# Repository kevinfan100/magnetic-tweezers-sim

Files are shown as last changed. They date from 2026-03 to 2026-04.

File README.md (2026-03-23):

# Magnetic Tweezers Simulation

ANSYS APDL magnetostatic finite element simulation of hexapole magnetic tweezers for biophysics research.

## Overview

This project implements FEM simulation of a 6-pole magnetic tweezers device, computing the magnetic field (B) under unit-excitation for each coil. Results feed into a point-charge model fitting pipeline for force calibration.

Based on: **Fei Long, "Design, Fabrication, and Calibration of a Hexapole Magnetic Tweezers," PhD Dissertation, Ohio State University, 2016.**

## Repository Structure

```
magnetic-tweezers-sim/
├── hexapole-long2016/       Long 2016 dissertation hexapole design
│   ├── apdl/                ANSYS APDL simulation & extraction scripts
│   ├── analysis/            MATLAB fitting & figure scripts
│   ├── data/                Fitting results (.mat)
│   ├── figures/             Publication figures (.png)
│   ├── docs/                Technical documentation
│   └── results/             ANSYS output (gitignored, ~10 GB/coil)
│
├── studies/                 Parametric & comparison studies
│   └── single-pole-yoke/   Yoke effect on single-pole B field
│
├── references/              Literature notes & paper management
│   ├── notes/               Structured Markdown notes (tracked)
│   ├── pdfs/                Original papers (gitignored)
│   └── texts/               pdftotext extracts (gitignored)
│
└── (future: hexapole-<name>/)  Additional hexapole designs
```

## Prerequisites

- **ANSYS MAPDL** 2025 R2 (or compatible version)
- **MATLAB** R2024b+ (Optimization Toolbox for fitting)
- ~60 GB disk space for full simulation results (6 coils)

## Quick Start

Run a single coil simulation (batch mode):
```bash
cd hexapole-long2016
"C:\Program Files\ANSYS2025R2\v252\ansys\bin\winx64\MAPDL.exe" -b -np 4 -m 24000 \
  -dir "results/coil1" -j "coil1" \
  -i "$(pwd)/apdl/MT_Modeling_Geometry_Meshing_Solving_Coil1.txt" \
  -o "results/coil1/solve.out"
```

Process results in MATLAB:
```matlab
cd hexapole-long2016/analysis
fit_charge_model        % [A] baseline fit
fit_all6_with_bias      % [B-6x] final 19-parameter fit
```

## Key Results (hexapole-long2016)

| Method | Parameters | Error | R_a (A/Wb) |
|---|---|---|---|
| [A] Baseline | ell=835 um | 4.94% | 9.21e8 |
| [J] Joint 6-coil | ell=766-818 um | 1.11% | ~1.01e9 |
| [B-6x] Final | 19 params | 0.07% | 1.03e9 |

## References

- Long, F. (2016). PhD Dissertation, Ohio State University.
- Zhang, Z. & Menq, C.H. (2011). IEEE/ASME Trans. Mechatronics.
- Long, F., Matsuura, T. & Bhatt, D. (2016). Actively Controlled Hexapole Electromagnetic Actuating System.

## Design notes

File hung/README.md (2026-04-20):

# Hung Hexapole Magnetic Tweezers — FEM Simulation

## Overview
ANSYS APDL magnetostatic simulation of the Hung hexapole magnetic tweezers design.
6 tilted poles on a R=0.5mm sphere at magic angle (54.74°), with 1018 steel (mu_r=280).

## Folder Structure

```
hung/
├── apdl/              APDL scripts
│   ├── MT_Hung_Simulate_Coil[1-6].txt        Original D-shape poles
│   ├── MT_Hung_Simulate_Coil1_filleted.txt    D-shape + R=40um fillet
│   ├── MT_Hung_Simulate_Coil1_filled.txt      Full-round sharp tip
│   ├── MT_Hung_Simulate_Coil1_round_filleted.txt  Full-round + R=40um fillet
│   ├── MT_Hung_SphereModel*.txt               IGES export scripts
│   ├── mesh_steel_only.txt                    Steel-only mesh (no air domain)
│   └── post_*.txt                             Post-processing scripts
├── analysis/          MATLAB scripts: data import, figure generation
├── comsol/            COMSOL models (gitignored)
├── docs/              Technical documentation
├── figures/
│   ├── analytic/      Analysis figures (sensor, fitting, parameter sweeps)
│   ├── geometry/      3D geometry annotations
│   ├── coil1/         Coil 1 B-field distribution figures
│   │   └── fail/      Rejected figures
│   └── coil2~6/       (empty, for future coil simulations)
│       └── fail/
├── IGES/              IGES exports: raw ANSYS output (unit flag=6)
├── IGES_converted/    IGES exports: unit flag=1 (SolidWorks compatible)
├── results/           ANSYS outputs (gitignored, ~10GB each)
└── scripts/           Utility scripts
```

## Pole Variants

| Script | Pole Shape | Tip | Status |
|---|---|-----|---|
| `Simulate_Coil1.txt` | D-shape | Sharp | Baseline |
| `Simulate_Coil1_filleted.txt` | D-shape + R=40um fillet | Rounded | Main model |
| `Simulate_Coil1_filled.txt` | Full-round | Sharp | Tested |
| `Simulate_Coil1_round_filleted.txt` | Full-round + R=40um fillet | Rounded | Tested |

## Design Parameters

| Parameter | Value |
|---|---|
| R_sphere | 0.5 mm |
| TILT_UP (P2,P4,P5) | 35° |
| TILT_DN (P1,P3,P6) | 5.71° |
| Pole total length | 43.0 mm |
| Pole shaft radius | 3.175 mm |
| Pole cone length | 15.875 mm |
| Tip fillet radius | 40 um |
| Coil R_in / R_out | 10 / 12 mm |
| Coil height | 15 mm |
| Turns | 70 |
| Steel mu_r | 280 |

## Key Results (Coil1, 70 A-turns, D-shape + fillet)

| Location | |B| |
|---|-----|
| WP center | 9.66 mT |
| P1 tip surface | 424 mT |
| Iron max (guide post) | 1493 mT |
| P1 surface (s=15.75mm) | 2.82 mT |

## Quick Start

```bash
cd hung

# Run simulation (D-shape + fillet, coil 1)
MAPDL -b -np 2 -m 8000 -dir "results/coil1/filleted" -j "coil1" \
  -i "apdl/sim/MT_Hung_Simulate_Coil1_filleted.txt" \
  -o "results/coil1/filleted/solve.out"

# Export B-field data
MAPDL -b -np 1 -m 4000 -dir "results/coil1/filleted" -j "coil1" \
  -i "apdl/postproc/post_export_data.txt"

# Generate figures (MATLAB)
run('analysis/generate_figures.m')
```

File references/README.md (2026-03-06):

# References

Reference papers for the magnetic tweezers ANSYS simulation project.

## How This Works

This folder uses a **notes-first** strategy for working with Claude Code:

| Tier | When | Action |
|---|---|---|
| **1. Notes** | 95% of cases | Read `notes/*.md` directly |
| **2. Targeted text** | Notes lack detail | Read `texts/*.txt` at specific line range (use `_page_index.txt` to locate pages), then update notes |
| **3. Full intake** | New paper added | Convert PDF via `pdftotext -layout`, read TOC, build skeleton note, deep-read key sections |

## Paper Index

<!-- Add papers here as they are processed. Citation key = note filename without .md -->

| Citation Key | Authors | Year | Type | Tags | Note Status |
|---|---|---|---|---|---|
| zhang-dissertation | Zhipeng Zhang | 2009 | PhD Dissertation | force-modeling, monopole-approximation, magnetic-circuit, calibration, quadrupole | complete |
| long-2016-dissertation | Fei Long | 2016 | PhD Dissertation | geometry, materials, fem-simulation, calibration, force-model, inverse-model, pole-naming, coil-design, superposition, hall-sensor | complete |
| zhang-2011-actuator-design | Z. Zhang, C.-H. Menq | 2011 | journal | geometry, materials, force-model, superposition, coil-design, pole-configuration, magnetic-circuit, inverse-model, calibration | complete |
| long-2016-active-control | F. Long, D. Matsuura, C.-H. Menq | 2016 | journal | geometry, materials, fem-simulation, calibration, force-model, inverse-model, optimal-control | complete |

## Topic Index

### Geometry & Device Design
- [zhang-dissertation](notes/zhang-dissertation.md) -- Quadrupole design: pole material (MuShield), dimensions, yoke
- [long-2016-dissertation](notes/long-2016-dissertation.md) -- Hexapole design: 1018 steel poles (40 um tip), 70-turn coils, 6-pole geometry, workspace 500 um
- [zhang-2011-actuator-design](notes/zhang-2011-actuator-design.md) -- Hexapole design: Ni-Fe-Mo foil poles (40 um tip, 178 um thick), 50-turn AWG#24 coils, rho=594 um, two-layer config
- [long-2016-active-control](notes/long-2016-active-control.md) -- Same 1018 steel hexapole as Long diss; FEM mesh in Fig. 2(b) is our ANSYS reference

### Materials & Magnetic Properties
- [zhang-dissertation](notes/zhang-dissertation.md) -- MuShield Ni-Fe-Mo alloy (mu_R=36000), cold rolled steel yoke (mu_R=5000), saturation ~0.9T
- [long-2016-dissertation](notes/long-2016-dissertation.md) -- 1018 low-carbon steel (>2T saturation), air reluctance 6.3e8 A/Wb, nonlinear B-H modeling
- [zhang-2011-actuator-design](notes/zhang-2011-actuator-design.md) -- Ni-Fe-Mo alloy poles (B_sat ~2.1 T), cold-rolled steel yoke, AWG#24 wire
<!--  -->

### FEM Simulation Methods
- [long-2016-dissertation](notes/long-2016-dissertation.md) -- ANSYS APDL magnetostatic, SOLID96/SOURC36, unit-excitation superposition, 6-solve approach
- [zhang-2011-actuator-design](notes/zhang-2011-actuator-design.md) -- References FEM for reluctance calibration (R_a=2.8e9 A/Wb), no FEM details given (see [18])
<!--  -->

### Calibration & Force Measurement
- [zhang-dissertation](notes/zhang-dissertation.md) -- PSD-based calibration, saturation current, inverse force model validation
- [long-2016-dissertation](notes/long-2016-dissertation.md) -- Flux distribution matrix K_I calibration, Hall-sensor force model, Langevin bead magnetization
- [zhang-2011-actuator-design](notes/zhang-2011-actuator-design.md) -- PSD-based k_I_hat calibration (0.53 pN at 1.2A), Brownian motion validation
<!--  -->

### Superposition & Field Computation
- [zhang-dissertation](notes/zhang-dissertation.md) -- Monopole approximation, superposition principle, quadratic force model F=Q^T*M*Q
- [long-2016-dissertation](notes/long-2016-dissertation.md) -- Magnetic charge model, quadratic force F=g*I^T*K^T*L*K*I, optimal inverse model, least-square position fitting
- [zhang-2011-actuator-design](notes/zhang-2011-actuator-design.md) -- Magnetic charge model, K_I matrix (5/6, 1/6), quadratic force F_hat=I_hat^T*N*I_hat, inverse model
<!--  -->

## Expected PDF Files

The following PDFs should be placed in `pdfs/` (gitignored, not tracked):

- `Design_and_Modeling_of_a_3-D_Magnetic_Actuator_for_Magnetic_Microbead_Manipulation.pdf` — Zhang & Menq, IEEE/ASME Trans. Mechatronics, 2011 (10 pp.)
- `Actively_Controlled_Hexapole_Electromagnetic_Actuating_System_Enabling_3-D_Force_Manipulation_in_Aqueous_Solutions.pdf` — (12 pp.)
- `Fei Long_dissertation.pdf` — Long, PhD Dissertation, Ohio State University, 2016 (167 pp.)
- `Zhipeng Zhang.pdf` — Zhang, PhD Dissertation (165 pp.)

## Text Extraction

PDFs are converted to text using Poppler's `pdftotext -layout` and stored in `texts/` (gitignored).
Each text file has a `_page_index.txt` that maps PDF page numbers to line numbers.

To regenerate all text files:
```bash
PBIN="C:/Users/pmero/AppData/Local/Microsoft/WinGet/Packages/oschwartz10612.Poppler_Microsoft.Winget.Source_8wekyb3d8bbwe/poppler-25.07.0/Library/bin"
for f in references/pdfs/*.pdf; do
  "$PBIN/pdftotext.exe" -layout "$f" "references/texts/$(basename "$f" .pdf).txt"
done
```

## Adding a New Paper

1. Place PDF in `pdfs/` with naming convention: `firstname-year-short-topic.pdf`
2. Run `pdftotext -layout` to generate text extract in `texts/`
3. Generate page index: `awk 'BEGIN{page=1; print "Page 1: line 1"} /\f/{page++; print "Page " page ": line " NR}' texts/name.txt > texts/name_page_index.txt`
4. Copy `notes/_TEMPLATE.md` to `notes/firstname-year-short-topic.md`
5. Read the TOC from text file and build a skeleton note
6. Fill in key sections based on project needs
7. Update the Paper Index and Topic Index tables above

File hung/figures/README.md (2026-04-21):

# Hung Hexapole — Figures

## Folder Structure

```
figures/
├── coil1/ ~ coil6/    B-field distribution plots per single-coil excitation
│   └── fail/          Rejected or superseded versions of those plots
├── analytic/          Analysis figures: fitting, geometry, sensor sensitivity
└── README.md          This file
```

**Convention** (per project figure-organization rule):
- Successful distribution plots go in the `coilN/` root and **overwrite the previous file with the same name**.
- Rejected / superseded versions move to `coilN/fail/`.
- Analysis, parameter-sweep, geometry-annotation, and sensor-study figures live in `analytic/` (not coil-specific).

Currently only **coil1/** has populated B-field plots; coil2–6 have empty `fail/` subfolders reserved.

## coil1/ — B-field plots (D-shape + 40 µm fillet, 70 A-turns)

| File | Description |
|---|---|
| `Bvector_topview.png` | Top-view B-field vectors over the full model (±80 mm, Tesla) |
| `Bvector_topview_mT.png` | Same top view, rescaled to mT (close-up near working point) |
| `Bvector_3D_iron.png` | 3D B-field arrows inside iron only, showing flux circulation |
| `Bcontour_P1_topview.png` | \|B\| contour at P1 tip top view |
| `Bcontour_xaza_Dfillet.png` | \|B\| contour on x_a-z_a plane (y_a=0), D+fillet 3-pass NREFINE data, 2D slab interpolation. Actuator frame: x_a→P1, y_a→P3, z_a→P5 |
| `Bcontour_xaza_Dfillet_smooth.png` | Same view, upgraded with 3D interpolation + Gaussian smoothing; clearest production version (WP = 8.74 mT, 526,645 nodes) |
| `Bcontour_xaza_Dshape_baseline.png` | Same view, D-shape **no fillet / no NREFINE** baseline (368,686 nodes, WP = 9.31 mT) — shown as convergence contrast to `_smooth` |

## analytic/ — Fitting & analysis figures

### Point-charge model fitting
| File | Description |
|---|---|
| `charge_model_cost_landscape.png` | Method [A] cost vs ell (1D search landscape) |
| `charge_positions_J.png` | 6 fitted charge positions from Method [J] ideal K_I |
| `charge_projection_lower_upper.png` | Lower/Upper charge projection schematic (s, θ, l relationship) |
| `fitting_J_idealKI_quiver_error.png` | [J] ideal K_I: FEM vs model quiver + % error scatter |
| `fitting_J_idealKI_RMSE.png` | [J] ideal K_I: FEM vs model quiver + RMSE (mT) |
| `fitting_J_idealKI_50um_RMSE.png` | [J] ±50 µm cube (Long-compatible) + RMSE |
| `fitting_B6x_quiver_error.png` | [B-6x] alternating superposition: FEM vs model quiver + error |

### Direction vectors (d̂)
| File | Description |
|---|---|
| `dhat_vs_pole_axis.png` | d̂ (WP→charge) vs pole axis direction, Hung |
| `dhat_vs_pole_axis_Long.png` | Same comparison for Long 2016 (reference) |
| `dhat_3D_Long.png` | 3D view of Long 2016 d̂ vectors |

### Hall-sensor analysis
| File | Description |
|---|---|
| `sensor_sensitivity_full.png` | Sensor sensitivity vs position, full range with installable annotation |
| `sensor_sensitivity_vs_position.png` | Same, zoomed to installable range |
| `sensor_ratio_fit.png` | Sensitivity ratio fit curve |
| `sensor_ratio_vs_distance.png` | Sensitivity ratio vs sensor-to-WP distance |
| `sensor_Btop_full_range.png` | B-field magnitude at sensor top surface, full range |
| `sensor_Btop_vs_position.png` | Same, zoomed |

### Geometry annotations
| File | Description |
|---|---|
| `hexapole_tip_annotated.png` | 6 pole tips on R=0.5 mm sphere with P1–P6 labels and l annotation |
| `mesh_steel_filleted_3D.png` | 3D mesh visualization of steel body (D-shape + fillet, no yoke) |

### Mesh convergence
| File | Description |
|---|---|
| `WP_convergence_Hung.png` | WP \|B\| vs total mesh node count: baseline (no NREFINE, 368k, 9.31 mT) → 3-pass NREFINE (526k, 8.74 mT); Richardson asymptote ≈ 8.60 mT |

## Generating Figures

Paths reflect the current post-reorg structure:

```bash
# Step 1: Run ANSYS simulation (D-shape + fillet, coil1)
cd hung/
"C:\Program Files\ANSYS2025R2\v252\ansys\bin\winx64\MAPDL.exe" -b -np 4 -m 8000 \
  -dir "results/coil1/filleted" -j "coil1" \
  -i "apdl/sim/MT_Hung_Simulate_Coil1_filleted.txt" \
  -o "results/coil1/filleted/solve.out"

# Step 2: Export B-field data for MATLAB
"C:\Program Files\ANSYS2025R2\v252\ansys\bin\winx64\MAPDL.exe" -b -np 1 -m 4000 \
  -dir "results/coil1/filleted" -j "coil1" \
  -i "apdl/postproc/post_export_data.txt"

# Step 3: Generate plots in MATLAB
cd analysis/plot
# In MATLAB:
#   run('plot_Bfield_2d.m')      -> figures/ root (move to figures/coil1/)
#   run('plot_Bfield_3d.m')      -> Bvector_3D_iron.png
#   run('plot_J_quiver.m')       -> figures/analytic/fitting_J_idealKI_quiver_error.png
#   run('plot_J_rmse.m')         -> figures/analytic/fitting_J_idealKI_RMSE.png
#   run('plot_charge_proj.m')    -> figures/analytic/charge_projection_lower_upper.png
#   run('plot_Bcontour_xaza.m')          -> figures/coil1/Bcontour_xaza_Dfillet_smooth.png
#   run('plot_Bcontour_xaza_baseline.m') -> figures/coil1/Bcontour_xaza_Dshape_baseline.png
```

Note: `plot_Bfield_2d.m` and `plot_Bfield_3d.m` save to the `figures/` root — manually move the output into the appropriate `coilN/` subfolder after each run.

## Simulation Parameters

| Parameter | Value |
|---|---|
| Excitation | 70 A-turns (TURNS=70, I=1 A) |
| Steel mu_r | 280 (linear, constant) |
| Pole shape | D-shape + 40 µm diameter tip fillet |
| Mesh | tips fine → steel ~ coarse air |
| Solver | magsolv,3 (DSP) |

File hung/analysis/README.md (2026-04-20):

# MATLAB Analysis Scripts

## Prerequisites
- Run ANSYS simulation first (`MT_Hung_Simulate_CoilN_filleted.txt`) for all 6 coils
- Run data export (`post_export_data_coilN.txt`) to produce `.dat` files in `results/coilN/filleted/`

## Directory Structure

```
hung/analysis/
├── core/        Shared utilities (constants, data loader)
├── fit/         Charge-model fitting pipeline ([pre-J] → [J] → [B-6x])
├── plot/        Figure generation (B-field, quiver error, RMSE, projection)
├── util/        Small helpers (position printout)
└── variants/    Alternative or previous-version scripts (not actively used but may be revisited)
```

## Scripts

### core/ — shared utilities
| File | Description |
|---|---|
| `mt_constants.m` | Hung hexapole design constants: R_norm, tip positions, yoke dimensions, pole angles |
| `import_ansys_data.m` | Read ANSYS-exported coordinate + B-field `.dat` files. Handles MAPDL banner headers and concatenated negative numbers. Returns struct with node_id, x, y, z, bx, by, bz, bsum |

### fit/ — fitting pipeline
Run in this order. Each script is independent but later steps load outputs from earlier ones.

| Order | File | Output | Description |
|---:|---|---|---|
| 1 | `fit_ell_percoil.m` | `single_charge_ell.mat` | Per-coil single-charge ell sweep (no K_I), gives rough |l| per pole |
| 2 | `fit_ell_perlayer.m` | `KI_fit.mat` | Per-layer ell averages + sphere `pos` initial values for [J] |
| 3 | `fit_J.m` | `J_ideal_fit.mat` | **[J] Joint 6-coil fit with ideal K_I** — main result (err ~0.46%). Needed as init by B6x_1C/6C. |
| 3a | `fit_J_50um.m` | `J_idealKI_50um.mat` + figure | [J] restricted to ±50 μm cube (Long-compatible) + RMSE figure |
| 4 | `fit_B6x_1C.m` | `B6x_hung_1C.mat` | [B-6x] 18 pos + 1 shared C (VarPro). Loads `J_ideal_fit.mat` and `KI_fit.mat`. |
| 4a | `fit_B6x_6C.m` | `B6x_hung_6C.mat` | [B-6x] 18 pos + 6 per-pole C (linear LS). Same loads as 4. |
| 4b | `fit_B6x_allcoil.m` | `all6_bias_fit.mat` | [B-6x] all-coil superposition, requires `charge_model_fit.mat` (no Hung producer — see `data/README.md`) |

### plot/ — figures
| File | Output | Description |
|---|---|---|
| `plot_Bfield_2d.m` | `figures/Bvector_topview.png`, `Bfield_xy.png`, `Bfield_xz.png` | Long2016-style vector + contour plots |
| `plot_Bfield_3d.m` | `figures/Bfield_3d.png` | 3D B-field arrow plot (iron flux flow) |
| `plot_J_quiver.m` | `figures/analytic/fitting_J_idealKI_quiver_error.png` | [J] FEM vs Model quiver + % error |
| `plot_J_rmse.m` | `figures/analytic/fitting_J_idealKI_RMSE.png` | [J] FEM vs Model quiver + RMSE (mT) |
| `plot_charge_proj.m` | `figures/analytic/charge_projection_lower_upper.png` | Lower/Upper charge projection schematic |

### util/
| File | Description |
|---|---|
| `print_J_positions.m` | Print per-pole positions table from [J] ideal K_I fit |

### variants/ — alternative versions, kept available for future use
These are not part of the current main pipeline, but are kept intact (paths already adjusted) so you can re-run them when needed (e.g., to re-check a previous method against the current main one, or to explore an alternative).

| File | Current main | Context / when to use |
|---|---|---|
| `fit_KI_v1.m` | `fit/fit_ell_perlayer.m` | v1 uses single ell from method [A]; v2 uses per-layer ell. Re-run v1 if you want to compare the single-ell path. |
| `fit_J_fittedKI.m` | `fit/fit_J.m` | Uses **fitted** K_I; main pipeline uses **ideal** K_I (0.46% error, confirmed sufficient). Re-run if you want to revisit non-ideal K_I behaviour. |

## Path Mechanism

Each active script adds `core/` to the MATLAB path automatically:

```matlab
addpath(fullfile(fileparts(mfilename('fullpath')), '..', 'core'));
```

This lets you `cd` into `fit/` (or `plot/`, `util/`) and run scripts directly without prior setup.

## Usage Example

```matlab
% Generate B-field figures for coil1
cd hung/analysis/plot
run('plot_Bfield_2d.m')
run('plot_Bfield_3d.m')

% Run full fitting pipeline
cd ../fit
run('fit_ell_percoil.m')     % produces single_charge_ell.mat
run('fit_ell_perlayer.m')    % produces KI_fit.mat (needed by later steps)
run('fit_J.m')               % produces J_ideal_fit.mat (needed by B6x_1C/6C)
run('fit_B6x_1C.m')          % [B-6x] with shared C
run('fit_B6x_6C.m')          % [B-6x] with per-pole C

% Plot fitting error
cd ../plot
run('plot_J_quiver.m')
run('plot_J_rmse.m')
```

Output `.mat` files go to `hung/data/`. Output `.png` files go to `hung/figures/` (2D/3D B-field) or `hung/figures/analytic/` (fitting error, projection).

## Data Format
The `.dat` files produced by `post_export_data_coilN.txt`:
- `coilN_coord_{all,wp}.dat` — node coordinates (NODE, X, Y, Z)
- `coilN_bfield_{all,wp}.dat` — B-field (NODE, BX, BY, BZ, BSUM)
- WP region = nodes within 2 mm of origin
- Units: SI (meters, Tesla)

## Figure Style (matching Long2016)
- Font: Helvetica, 12pt labels, 13pt titles
- Colormap: turbo(256)
- DPI: 300 (figures), 400 (3D)
- Contour: 20 levels, no line edges

## Legacy → New Filename Mapping

For anyone looking up old filenames referenced in git history or documentation:

| Old | New |
|-----|-----|
| `fit_single_charge.m` | `fit/fit_ell_percoil.m` |
| `fit_KI_v2.m` | `fit/fit_ell_perlayer.m` |
| `test_J_idealKI.m` | `fit/fit_J.m` |
| `fit_J_idealKI_50um.m` | `fit/fit_J_50um.m` |
| `fit_B6x_hung.m` | `fit/fit_B6x_1C.m` |
| `fit_B6x_perC.m` | `fit/fit_B6x_6C.m` |
| `fit_all6_with_bias.m` | `fit/fit_B6x_allcoil.m` |
| `generate_figures.m` | `plot/plot_Bfield_2d.m` |
| `generate_fig_3d.m` | `plot/plot_Bfield_3d.m` |
| `plot_J_idealKI.m` | `plot/plot_J_quiver.m` |
| `plot_J_idealKI_RMSE.m` | `plot/plot_J_rmse.m` |
| `plot_charge_projection.m` | `plot/plot_charge_proj.m` |
| `print_J_idealKI_positions.m` | `util/print_J_positions.m` |
| `fit_KI.m` | `variants/fit_KI_v1.m` |
| `fit_joint_6coil.m` | `variants/fit_J_fittedKI.m` |
| `plot_fitting_J.m` | *(deleted — obsolete figure also removed)* |

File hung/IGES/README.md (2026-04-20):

# IGES Part Exports

## Description
Individual part IGES files exported from ANSYS with SolidWorks-compatible units (MM=1/25.4).
SolidWorks reads values as inches x 25.4 = correct mm dimensions.

## Files

| File | Part | Key Dimensions |
|---|---|---|
| `Mag_Pole_Bottom.iges` | Magnetic pole (D-shape + cone) | R=3.175mm, cone=15.875mm, total=43mm, flat=28mm |
| `Pole_Block_Top.iges` | Upper block (L-shape) | 25x22x10mm, penetration=7mm |
| `Pole_Block_Bottom.iges` | Lower block (L-shape) | 22x22x10mm, penetration=4.5mm |
| `Mag_Guide_Post.iges` | Guide post cylinder | R=4mm, H=46mm |
| `Coil.iges` | Excitation coil ring | R_in=10mm, R_out=12mm, H=15mm |
| `Upper_Ring.iges` | Yoke (iron ring) | R_in=38mm, R_out=62.5mm, T=2mm |
| `Full_Assembly.iges` | Complete hexapole assembly | All parts assembled, unit flag=1 (inches) |
| `Mag_Pole_Bottom_filleted.iges` | Pole with 40 um diameter tip fillet (single part) | R_tip=20um, semi-angle 11.31°, junction at 15.793mm |
| `Full_Assembly_filleted.iges` | Complete assembly with 40 um tip fillet on all 6 poles | Same as above for all poles |

## STEP Conversion
To convert to STEP for other CAD software:
1. Open IGES in SolidWorks (dimensions will be correct mm)
2. File → Save As → .STEP

`Full_Assembly.iges` has unit flag fixed to 1 (inches) for reliable STEP conversion.

## Regenerating
When part dimensions change:
1. Update values in `hung/apdl/geom/export_parts.txt`
2. Run: `MAPDL -b -np 1 -m 2000 -dir "IGES" -j "parts" -i "apdl/geom/export_parts.txt"`
3. For full assembly: run `apdl/variants/MT_Hung_SphereModel.txt`, copy output to `Full_Assembly.iges`, fix unit flag with `sed -i "s/,1.0,6,,/,1.0,1,,/" Full_Assembly.iges`

## Filleted Versions (40 um diameter tip fillet)

The `_filleted.iges` versions add a 40 um diameter (20 um radius) spherical fillet at each pole tip,
replacing the mathematically sharp point with a smooth rounded tip.

**Why fillet?** Real machined parts cannot have R=0 sharp tips. EDM machining typically achieves
20-50 um. Adding a fillet matches reality and improves FEM mesh stability at the tip.

**Geometry (Method A — smooth tangent):**
- Foremost point of fillet at original tip position (preserves R=0.5mm sphere constraint)
- Cone semi-angle unchanged at 11.31° (matches original Hung STEP)
- Cone-cyl junction shifts back from 15.875 -> 15.793 mm (delta = 0.082 mm)
- Total pole length unchanged at 43 mm
- All other features (flat at 28mm, far end at 43mm, POLE_R=3.175mm) unchanged

**Constraints preserved:**
- All 6 fillet foremost points still on R=0.5mm sphere
- Orthogonal pair axes still 90 degrees
- tip-to-tip distance still 1.0 mm
- Magic angle 54.74 deg unchanged

**To regenerate:**
- Single pole: `MAPDL ... -i apdl/geom/export_pole_filleted.txt`
- Full assembly: `MAPDL ... -i apdl/geom/MT_Hung_Assembly_Dfillet.txt`

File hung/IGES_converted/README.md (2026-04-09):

# IGES Converted — Unit Flag Fixed

## Description
Same parts as `hung/IGES/`, but with IGES unit flag corrected from 6 (mm) to 1 (inches).
This ensures reliable conversion when saving as STEP in SolidWorks or other CAD software.

## Difference from `hung/IGES/`
- `hung/IGES/` — raw ANSYS export, unit flag = 6 (mm), values in inches. SolidWorks opens correctly but STEP conversion may fail.
- `hung/IGES_converted/` — unit flag fixed to 1 (inches). SolidWorks opens correctly AND STEP conversion preserves dimensions.

## Files

| File | Description |
|---|---|
| `Mag_Pole_Bottom.iges` | Magnetic pole (D-shape + cone) |
| `Pole_Block_Top.iges` | Upper block (L-shape) |
| `Pole_Block_Bottom.iges` | Lower block (L-shape) |
| `Mag_Guide_Post.iges` | Guide post (R=4mm, H=46mm) |
| `Coil.iges` | Excitation coil (R_in=10, R_out=12, H=15mm) |
| `Upper_Ring.iges` | Yoke ring (R_in=38, R_out=62.5, T=2mm) |
| `Full_Assembly.iges` | Complete hexapole assembly |
| `Mag_Pole_Bottom_filleted.iges` | Pole with 40 um diameter tip fillet (single part) |
| `Full_Assembly_filleted.iges` | Complete assembly with 40 um tip fillet on all 6 poles |

## Units
All files: values in inches, unit flag = 1 (inches).
SolidWorks reads as inches x 25.4 = correct mm dimensions.

## Regenerating
When parts change, re-export from `hung/IGES/` and fix unit flag:
```bash
cp hung/IGES/Part.iges hung/IGES_converted/Part.iges
sed -i "s/,1.0,6,,/,1.0,1,,/" hung/IGES_converted/Part.iges
```

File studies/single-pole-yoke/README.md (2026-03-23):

# Single-Pole Yoke Effect Study

Quantifies how the iron yoke affects the magnetic field of a single pole (P1).

## Comparison

| Metric | Case A (bare pole) | Case B (pole + yoke) | Ratio |
|---|---|---|---|
| B at WP center | 0.646 mT | 6.174 mT | 9.55x |
| Max B in WP | 18.3 mT | 213.8 mT | 11.7x |

## Key Findings

1. **Field Enhancement**: Yoke provides ~9.6x enhancement at workspace center
2. **Shape Preserved**: Normalized axial profile correlation = 0.9989 — yoke mainly affects magnitude, not spatial distribution
3. **Magnetic Circuit**: Simple series reluctance model underestimates the effect; yoke acts as a flux collector, not just a return path
4. **Effective R_a**: Bare pole R_a = 1.24e10, with yoke R_a = 1.29e9 (ratio matches field enhancement)

## Files

- `apdl/MT_SinglePole_Only.txt` — Case A: bare pole + coil, no yoke
- `apdl/MT_SinglePole_WithYoke.txt` — Case B: pole + coil + yoke
- `apdl/post_view_Bfield.txt` — POST1 visualization (GUI)
- `analysis/compare_yoke_effect.m` — V1 (enhancement) + V2 (distribution) + V3 (magnetic circuit)
- `data/yoke_comparison.mat` — Saved results
- `figures/` — B field contour and vector plots

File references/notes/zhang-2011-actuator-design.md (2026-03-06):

# Design and Modeling of a 3-D Magnetic Actuator for Magnetic Microbead Manipulation

## Bibliographic Info

| Field | Value |
|---|---|
| Authors | Zhipeng Zhang (Member, IEEE) and Chia-Hsiang Menq (Senior Member, IEEE) |
| Year | 2011 |
| Type | journal |
| Source | IEEE/ASME Transactions on Mechatronics, Vol. 16, No. 3, June 2011, pp. 421-430 |
| DOI/URL | 10.1109/TMECH.2011.2105500 |
| PDF file | `pdfs/Design_and_Modeling_of_a_3-D_Magnetic_Actuator_for_Magnetic_Microbead_Manipulation.pdf` |
| Total pages | 10 (pp. 421-430) |
| Received | July 14, 2010; revised October 29, 2010; accepted December 10, 2010; published February 10, 2011 |
| Affiliation | Department of Mechanical and Aerospace Engineering, The Ohio State University, Columbus, OH 43210 |
| Funding | NIH Grant R21RR024435 |

## Relevance to This Project

This is the **primary reference** for our ANSYS magnetic tweezers simulation. It describes the exact hexapole magnetic actuator we are modeling: the geometry, pole configuration, materials, coil specifications, magnetic circuit analysis, and force model. Every geometric parameter, material choice, and pole naming convention in our APDL scripts originates from this paper.

**Tags:** geometry, materials, fem-simulation, force-model, superposition, coil-design, pole-configuration, magnetic-circuit, inverse-model, calibration

## Key Contributions

- Design and implementation of a hexapole magnetic actuator capable of 3-D manipulation of magnetic microbeads
- Derivation of a lumped-parameter magnetic force model based on "magnetic charge" assumption, yielding quadratic form F_hat = I_hat^T * N * I_hat
- Analysis of force generation capability using force envelopes and quantitative measures (anisotropy Gamma, minimum envelope force F_min)
- Derivation of a simplified inverse force model (linear) for real-time feedback control: I_hat = D*(F_hat - U*P) + E
- Experimental validation via feedback-controlled Brownian motion analysis of a 2.8 um bead
- Force gain k_I_hat calibrated to 0.53 pN at I_max = 1.2 A
- Hexapole configuration obtained by rotating three orthogonal pole pairs to free the optical path

## Detailed Notes by Section

### I. Introduction (pp. 1-2, lines 1-134)

Context: Magnetic microbeads used in biophysics for DNA manipulation, cell mechanics, intracellular probing. Magnetic actuators categorized by number of poles:
- 1-pole: attractive force only toward tip [2, 10, 16, 17]
- 2-pole: forward/backward along one axis [1, 11]
- 3-pole (120 deg apart) or 4-pole (quadrupole): 2-D force [3, 18, 19]
- 6-pole: 3-D force [9, 20] -- this paper

Challenge: Force model for multipolar actuators is difficult because (1) mutual magnetization between poles, (2) force depends on field gradient. Previous work: quadrupole model [18] and feedback control [19] for 2-D. This paper extends to 3-D hexapole.

Paper organization: Section II = design and implementation, Section III = force model and capability, Section IV = inverse force model, Section V = experimental validation, Section VI = conclusion.

### II. Actuator Design and Implementation (pp. 2-3, lines 121-197)

#### A. Design Concept (pp. 2-3, lines 123-168)

The actuator consists of:
1. Six sharp-tipped magnetic poles concentrating flux into workspace
2. Six individual actuating coils (one per pole)
3. A magnetic yoke connecting all coils and poles (completes magnetic circuit)

**Hexapole configuration:** Six poles are NOT in the same plane, but in two layers [Fig. 1(b)]:
- Three dark-colored poles on a plane BELOW the specimen
- Three light-colored poles on a plane ABOVE the specimen
- The specimen (in a cell chamber between two coverslips) is in the workspace between the two layers

**Coordinate rotation:** Starting from 3 orthogonal pairs [Fig. 2(a)] where two poles along z-axis would block the optical path, a coordinate rotation yields the hexapole configuration [Fig. 2(b)] with all poles on two horizontal planes, leaving the optical path clear.

**Two coordinate frames defined [Fig. 2]:**
- Actuation coordinate frame: {O; x_a, y_a, z_a} -- aligned with pole pair axes
- Measurement coordinate frame: {O; x_m, y_m, z_m} -- aligned with microscope axes

**Rotation matrix** (left-multiply transforms measurement frame to actuation frame):

```
        [ 1/sqrt(6)   -1/sqrt(2)   -1/sqrt(3) ]
a_m R = [ 1/sqrt(6)    1/sqrt(2)   -1/sqrt(3) ]
        [ 2/sqrt(6)       0         1/sqrt(3) ]
```

**Pole locations in actuation frame:** The six poles are at [+/-rho, 0, 0], [0, +/-rho, 0], [0, 0, +/-rho], where rho = distance from workspace center to each pole tip.

**Pole numbering [Fig. 2(b)]:** P1 through P6 labeled in the figure. This is the paper pole convention. The pole indices and their positions in the measurement frame are critical for our simulation (see MEMORY.md for APDL-to-paper mapping).

#### B. Implementation (pp. 3-4, lines 170-196)

**Pole material:**
- High-permeability magnetic foils, 178 um thick (p. 3)
- Material: nickel-iron-molybdenum alloy (p. 3)
- Properties: high permeability, minimum hysteresis loss (p. 3)
- Saturation induction: ~2.1 T (p. 3, line 177)
- Machined by wire electrical discharge machining (wire EDM) (p. 3)
- Pole tip radius: ~40 um (p. 3, line 180)

**Pole assembly:**
- Three poles glued onto a No. 1 coverslip (thickness 0.13-0.15 mm) with low-viscosity epoxy [Fig. 3(a)]
- Pole tips form an equilateral triangle, side length ~840 um (p. 3, line 183)
- Other three poles fixed on a 1.2 mm thick glass slide [Fig. 3(b)]
- Two layers fixed face-to-face [Fig. 3(c)]
- Distance between two layers controlled by spacers: 508 um (p. 3, line 190)
- Resulting distance from workspace center to each pole: rho = 594 um (p. 3, line 193)

**Cell chamber:**
- Formed by stacking: No. 1 coverslip + seal ring (120 um thick) + No. 1 coverslip (p. 3, lines 194-195)
- Sealed with water solution containing suspended magnetic microbeads

**Magnetic yoke:**
- Shape: square loop with six protrusions for coil assembly (p. 3, line 175)
- Material: cold-rolled steel (p. 3, line 177)

**Coils:**
- Wire: AWG #24 magnetic wire, diameter = 0.51 mm (p. 3, line 178-179)
- Turns: 50 turns per coil (p. 3, line 180)
- Wound by hand (p. 3, line 178)

**Power amplifiers:**
- Model: BTA-18V-6A (Precision Micro Dynamics) (p. 3, line 182)
- Configuration: current mode (p. 3)
- Proportional gain: 0.3 A/V (p. 3, line 183)

**Microscope integration:**
- Inverted microscope: Nikon TE2000-U (p. 3, line 187)
- Setup thickness < 10 mm, fits between high-NA objective and high-NA condenser (p. 3, lines 188-189)

### III. Magnetic Force Model (pp. 3-6, lines 198-348)

#### A. Theoretical Derivation (pp. 4-5, lines 212-286)

**Magnetic charge assumption:** Each sharp-tipped pole generates a field that appears (from the workspace) as though from a point source. Total field = superposition of six point magnetic charges. Sum of all charges = 0 (no net charge). This is an extension of the magnetic dipole model -- a "magnetic hexapole model."

**Equation (1) -- Magnetic field from point charges (p. 4):**
```
B = sum_{j=1}^{6} k_m * (q_j / r_j^2) * u_j
```
where:
- k_m = mu_0 / (4*pi) = 1.0e-7 N/A^2
- mu_0 = permeability of vacuum
- q_j = magnetic charge = Phi_j / mu_0 (Phi = magnetic flux)
- r_j = distance from charge j to magnetic particle
- u_j = unit vector from charge j to particle

**Magnetic circuit [Fig. 5] (p. 4):**
- F_mmf = N_c * I = magnetomotive force (N_c turns, current I)
- R_p = lumped reluctance of a magnetic pole
- R_y = lumped reluctance of 1/6 of the yoke
- R_a = lumped reluctance from pole tip to workspace center in air
- Since yoke and poles are much more permeable than air: R_a >> R_p, R_y
- Simplification: neglect R_p and R_y

**Equation (2) -- Charges from currents (p. 4):**
```
Q = (N_c / (mu_0 * R_a)) * K_I * I
```
where:
- Q = [q1, q2, ..., q6]^T
- I = [I1, I2, ..., I6]^T
- K_I = 6x6 magnetic flux distribution matrix
- K_I diagonal terms = 5/6, off-diagonal terms = 1/6

**Reluctance value:** R_a = 2.8e9 A/Wb, determined by comparing analytical field (Eq. 1) with FEM results [18] (p. 4, line 247). Alternatively, R_a is lumped into k_I_hat for experimental calibration (approach adopted in this paper).

**Calculated magnetic field [Fig. 6]:** Field plotted in x_m-y_m and x_m-z_m planes when 1 A applied to coil of pole #5 (P5). Six poles drawn in scale. Dark poles above specimen, light poles below.

**Equation (3) -- Gradient force on superparamagnetic bead (p. 5):**
```
F = (1/2) * grad(m . B)
```
where m = (3V/mu_0) * ((mu - mu_0)/(mu + 2*mu_0)) * B is the effective magnetization.

**Equation (4) -- Normalized force model (quadratic form) (p. 5):**
```
F_hat = F / k_I_hat = I_hat^T * N * I_hat
```
where:
- F_hat = normalized 3x1 force vector (dimensionless)
- k_I_hat = lumped force gain (unit: Newton) -- contains bead properties, magnetic circuit properties, and I_max
- I_hat = I / I_max = normalized 6x1 current vector, each element in [-1, 1]
- N = 6x6 position-dependent matrix, each element is a 3x1 dimensionless vector
- Details of N computation in reference [18]

**Key insight:** The force is QUADRATIC (nonlinear) in the currents, even though the magnetic field is LINEAR in currents.

#### B. Magnetic Force Generation Capability (pp. 5-6, lines 337-348)

**Force envelopes [Fig. 7]:** At any location, all possible force vectors from all current combinations are computed. The end points fill a closed volume (force envelope).
- At workspace center [0,0,0]: symmetric envelope, zero force at center of volume
- Away from center: envelope deforms, stretched toward nearest pole
- Zero force point always inside envelope => can generate force in ANY direction

**Quantitative measures:**
1. **Force generation anisotropy Gamma:** ratio of smallest to largest force magnitude
   - Maximum Gamma = 0.58 at workspace center (p. 5, line 338)
   - Decreases moving away from center toward any pole
   - Contour surfaces [Fig. 8]: Gamma = 0.25 (innermost), 0.10 (middle), 0.04 (outermost)
   - For accurate force application, constrain Gamma > 0.1 => workspace within sphere of radius ~0.3 (normalized) (p. 6, line 403)

2. **Minimum envelope force F_hat_min:** magnitude of smallest force vector
   - Contour surface for F_hat_min = 3 shown in [Fig. 9]
   - Value 3 chosen because it is half the maximum force with inverse model (p. 6, line 412)

### IV. Inverse Force Model (pp. 6-8, lines 349-487)

#### A. Theoretical Derivation (pp. 6-7, lines 365-472)

**Problem:** Given desired force, find 6 currents. Underdetermined: 6 unknowns, 3 equations. Need 3 constraints.

**Constraint (5) -- Zero-sum current (p. 6):**
```
I_hat_1 + I_hat_2 + I_hat_3 + I_hat_4 + I_hat_5 + I_hat_6 = 0
```
Physical meaning: equal current to all coils produces zero net charge and zero field.

**Equation (6) -- Decoupled force at workspace center (p. 6):**
Under constraint (5), the force model at the center simplifies to:
```
a_F_hat_cx = 6 * (I_hat_1^2 - I_hat_2^2)
a_F_hat_cy = 6 * (I_hat_3^2 - I_hat_4^2)
a_F_hat_cz = 6 * (I_hat_5^2 - I_hat_6^2)
```
(In normalized actuation frame.) Normalized forces range: [-6, 6].

**Key observation:** Each force component depends on only ONE pair of opposing poles. This is the decoupled structure that makes the inverse model tractable.

**Equation (7) -- Linear inverse solution (p. 7):**
```
I_hat = D * a_F_hat_c + E
```
where:
```
      [ 1/8  -1/8   0     0     0     0  ]^T
D =   [ 0     0    1/8  -1/8    0     0  ]
      [ 0     0     0     0   -1/16  1/16]

E = [1/3, 1/3, 1/3, 1/3, -2/3, -2/3]^T
```
This introduces 3 constraints (mapping 3 force components to 6 currents).

**Equation (8) -- Constrained force model (p. 7):**
```
a_F_hat = (D * a_F_hat_c + E)^T * a_N * (D * a_F_hat_c + E)
```
No longer underdetermined; unique inverse solution possible.

**Equation (9) -- First-order Taylor approximation (p. 7):**
```
a_F_hat ~ a_F_hat_c + U * a_P
```
where U = diag(8, 8, 32) and a_P = normalized position in actuation frame.

**Equation (10) -- Simplified inverse force model (p. 7):**
```
I_hat ~ D * (a_F_hat - U * a_P) + E
```
Valid when bead is near workspace center and desired force is not very large.

#### B. Force Generation Capability with Inverse Model (pp. 7-8, lines 474-487)

**Force envelopes [Fig. 10]:** Smaller than unconstrained envelopes (Fig. 7). At [0,0,0.3], zero force point no longer inside envelope.

**Anisotropy contours [Fig. 11]:** Gamma = 0.25, 0.10, 0.04 surfaces all smaller than Fig. 8. A "degeneration boundary" (near Gamma = 0.04) exists beyond which force generation degenerates and stable feedback control is impossible.

**Minimum envelope force [Fig. 12]:** F_hat_min = 3 surface is smaller than Fig. 9.

**Conclusion:** Inverse model does not fully utilize actuator capability but provides a simple linear formula adequate for real-time control.

### V. Experimental Validation of the Force Model (pp. 8-9, lines 506-611)

**Experimental setup:**
- Microscope: Nikon TE2000-U with 60x dry objective lens (CFI Super Plan Fluor ELWD 60xC) (p. 8, line 520)
- Camera: high-speed CMOS, Mikrotron MC 1310 (p. 8, line 524)
- 3-D tracking via in-focus and off-focus image analysis [18, 19]
- Lateral measurement range: 200 um (limited by camera FOV) (p. 8, line 528)
- Axial measurement range: up to 18 um (limited by depth of focus) (p. 8, line 529)
- Sampling rate: 200 frames/s (p. 8, line 531)

**Magnetic bead:** 2.8 um diameter (M280, Dynal) (p. 8, line 538)

**Experiment: 3-D grid raster scan [Fig. 13]:**
- Grid: 5 x 5 x 3 locations (p. 8, line 543)
- Lateral step: 20 um; axial step: 5 um (p. 8, line 498)
- Maximum input current: I_max = 1.2 A (p. 9, line 504)
- Bead controlled at each location for 10 s; last 5 s of data used (after transient vanishes)
- Brownian motion restricted within +/- 210 nm (p. 8, line 495)

**Langevin equation (11) (p. 9):**
```
m * x_ddot(t) + gamma * x_dot(t) = F_T(t) + F_x(t)
```
- m = bead mass (negligible inertia for microscopic particle)
- gamma = damping coefficient in water
- F_T = random thermal (Langevin) force (zero mean, white noise)
- F_x = applied magnetic force

At steady state with constant set point: mean damping force -> 0, so mean magnetic force = 0. This provides validation.

**Results [Fig. 14, 15]:**
- Steady-state currents vary with position as expected from inverse model
- Calculated magnetic forces from measured currents and positions are very close to zero in all three directions
- Fluctuations in currents and forces are due to controller compensating thermal forces
- This **partially verifies** the force model accuracy

**Force gain calibration (p. 9, line 606):**
- Method: PSD analysis of controlled Brownian motion to determine loop gain
- k_I_hat = 0.53 pN at I_max = 1.2 A
- Force range = k_I_hat * force envelopes (Figs. 7 and 10)

### VI. Conclusion (pp. 9-10, lines 614-617)

Summary of contributions. The developed micromanipulator can apply controlled 3-D forces to magnetic microbeads for probing biological samples and characterizing 3-D mechanical properties.

## Equations and Parameters We Use

### Geometric Parameters

| Parameter | Value | Context | Page |
|---|---|---|---|
| Pole tip radius | ~40 um | Round tip of machined magnetic foil | 3 (line 180) |
| Pole foil thickness | 178 um | High-permeability magnetic foil | 3 (line 174) |
| Equilateral triangle side length | ~840 um | Formed by three pole tips on each layer | 3 (line 183-184) |
| Distance between two pole layers | 508 um | Controlled by spacer height | 3 (line 190) |
| Distance workspace center to pole (rho) | 594 um | Hexapole geometry after assembly | 3 (line 193) |
| Seal ring thickness | 120 um | Cell chamber spacing | 3 (line 195) |
| Coverslip thickness (No. 1) | 0.13-0.15 mm | Lower pole substrate | 3 (line 181) |
| Glass slide thickness | 1.2 mm | Upper pole substrate | 3 (line 185) |
| Setup total thickness | < 10 mm | Fits between objective and condenser | 3 (line 189) |

### Material Properties

| Parameter | Value | Context | Page |
|---|---|---|---|
| Pole material | Nickel-iron-molybdenum alloy | High permeability, low hysteresis | 3 (line 175) |
| Pole saturation induction | ~2.1 T | Pole material property | 3 (line 177) |
| Yoke material | Cold-rolled steel | Square loop yoke | 3 (line 177) |

### Coil Specifications

| Parameter | Value | Context | Page |
|---|---|---|---|
| Wire gauge | AWG #24 | Magnetic wire | 3 (line 178-179) |
| Wire diameter | 0.51 mm | AWG #24 | 3 (line 179) |
| Number of turns (N_c) | 50 | Per coil | 3 (line 180) |
| Maximum current (I_max) | 1.2 A | Experimental setting | 9 (line 504) |

### Magnetic Circuit Parameters

| Parameter | Value | Context | Page |
|---|---|---|---|
| k_m | mu_0/(4*pi) = 1.0e-7 N/A^2 | Magnetic constant | 4 (line 238) |
| R_a (air reluctance) | 2.8e9 A/Wb | From FEM comparison | 4 (line 247) |
| K_I diagonal | 5/6 | Flux distribution matrix | 4 (line 234) |
| K_I off-diagonal | 1/6 | Flux distribution matrix | 4 (line 235) |

### Force Model Parameters

| Parameter | Value | Context | Page |
|---|---|---|---|
| k_I_hat (force gain) | 0.53 pN | At I_max = 1.2 A, calibrated from Brownian motion PSD | 9 (line 606) |
| Max Gamma at center | 0.58 | Force generation anisotropy | 5 (line 338) |
| Gamma > 0.1 workspace radius | ~0.3 (normalized) | Practical workspace limit | 6 (line 403) |
| U matrix | diag(8, 8, 32) | Position-dependent linearization | 7 (line 463) |

### Key Equations

| Equation | Expression | Context | Page |
|---|---|---|---|
| (1) | B = sum k_m * (q_j/r_j^2) * u_j | Magnetic field from point charges | 4 |
| (2) | Q = (N_c/(mu_0*R_a)) * K_I * I | Charges from currents | 4 |
| (3) | F = (1/2) * grad(m . B) | Gradient force on superparamagnetic bead | 5 |
| (4) | F_hat = I_hat^T * N * I_hat | Normalized quadratic force model | 5 |
| (5) | sum(I_hat_i) = 0 | Zero-sum current constraint | 6 |
| (6) | F_hat_cx = 6*(I1^2 - I2^2), etc. | Decoupled force at center | 6 |
| (7) | I_hat = D * F_hat_c + E | Linear inverse at center | 7 |
| (9) | F_hat ~ F_hat_c + U*P | First-order Taylor approx. | 7 |
| (10) | I_hat ~ D*(F_hat - U*P) + E | Simplified inverse force model | 7 |
| (11) | m*x_ddot + gamma*x_dot = F_T + F_x | Langevin equation | 9 |

### Experimental Parameters

| Parameter | Value | Context | Page |
|---|---|---|---|
| Bead diameter | 2.8 um | Dynal M280 | 8 (line 538) |
| Bead type | M280 (Dynal) | Superparamagnetic | 8 (line 538) |
| Sampling rate | 200 frames/s | Control loop | 8 (line 531) |
| Lateral measurement range | 200 um | Camera FOV limited | 8 (line 528) |
| Axial measurement range | up to 18 um | Depth of focus limited | 8 (line 529) |
| Brownian motion amplitude | +/- 210 nm | Controlled bead at set point | 8 (line 495) |
| Power amplifier gain | 0.3 A/V | Current mode output | 3 (line 183) |
| Grid scan dimensions | 5 x 5 x 3 | Raster scan experiment | 8 (line 543) |
| Lateral step | 20 um | Grid spacing | 8 (line 498) |
| Axial step | 5 um | Grid spacing | 8 (line 498) |
| Dwell time per location | 10 s (last 5 s used) | Data collection | 8 (line 504) |

## Figures Worth Revisiting

| Figure | Page | Description | Why revisit |
|---|---|---|---|
| Fig. 1 | 2 | (a) Top-view design concept showing 6 poles; (b) side zoomed view showing two-layer arrangement | Understand physical layout, dark=below/light=above convention |
| Fig. 2 | 3 | (a) Orthogonal pole arrangement; (b) rotated hexapole config with pole numbering P1-P6, both coordinate frames shown | **Critical**: pole numbering convention, coordinate frame definitions |
| Fig. 3 | 3 | Assembly process: (a) top 3 poles on coverslip, (b) bottom 3 on glass slide, (c) face-to-face, (d) full setup with yoke and coils | Physical assembly reference, spacer arrangement |
| Fig. 4 | 3 | Photo of actuator on inverted microscope | Real device reference |
| Fig. 5 | 4 | Magnetic circuit diagram of hexapole actuator | Understand reluctance model, R_p, R_y, R_a definitions |
| Fig. 6 | 5 | Calculated B-field in x_m-y_m and x_m-z_m planes (1A to P5 coil), poles drawn in scale | **Critical**: compare with our ANSYS FEM results for verification |
| Fig. 7 | 5 | Force envelopes at [0,0,0], [0.3,0,0], [0,0,0.3] (unconstrained) | Force capability analysis |
| Fig. 8 | 6 | Contour surfaces of anisotropy Gamma (0.25, 0.10, 0.04) | Workspace boundary determination |
| Fig. 9 | 6 | Contour surface of F_hat_min = 3 | Workspace force limit |
| Fig. 10 | 7 | Force envelopes with inverse model constraints | Compare with Fig. 7 to see constraint effect |
| Fig. 11 | 7 | Anisotropy contours with inverse model, degeneration boundary | Controllability limits |
| Fig. 12 | 8 | F_hat_min = 3 contour with inverse model | Compare with Fig. 9 |
| Fig. 13 | 8 | 3-D grid trajectory (5x5x3) in measurement frame | Experimental protocol |
| Fig. 14 | 9 | Steady-state currents I1, I3, I5 vs. grid position | Validation: currents vary with position |
| Fig. 15 | 9 | Calculated forces from applied currents -- should be ~0 | **Critical**: force model validation result |

## Cross-References

- [zhang-dissertation] -- Zhipeng Zhang PhD dissertation (2009, Ohio State University). Should contain extended details of the quadrupole work [18], FEM analysis, and possibly more geometric/material specifications.
- [long-dissertation] -- Fei Long PhD dissertation. Likely extends this hexapole work with additional experiments and control strategies.
- [18] Z. Zhang, K. Huang, and C.-H. Menq, "Design, implementation, and force modeling of quadrupole magnetic tweezers," ASME/IEEE Trans. Mechatronics, 2010. -- Contains details of matrix N computation and the quadrupole precursor.
- [19] Z. Zhang, Y. Huang, and C.-H. Menq, "Actively controlled manipulation of a magnetic microbead using quadrupole magnetic tweezers," IEEE Trans. Robot., 2010. -- Feedback control design and k_I_hat calibration method.

## Page Ranges for Claude

| Pages | Lines | Main Topic |
|---|---|---|
| 1 | 1-70 | Title, abstract, keywords, beginning of Introduction |
| 2 | 71-134 | Introduction (cont.), Design concept (Sec. II-A) begins |
| 3 | 135-197 | Design concept (coordinate rotation, frames), Implementation (Sec. II-B): materials, geometry, coils, yoke |
| 4 | 198-287 | Force model derivation (Sec. III-A): magnetic charge model, Eqs. (1)-(2), magnetic circuit, reluctance |
| 5 | 288-348 | Force model (cont.): Eqs. (3)-(4), force envelopes [Fig. 7], anisotropy Gamma |
| 6 | 349-431 | Anisotropy contours [Fig. 8], F_hat_min [Fig. 9], Inverse force model (Sec. IV-A) begins: constraint (5), Eq. (6) |
| 7 | 432-487 | Inverse model: Eqs. (7)-(10), D/E/U matrices, Taylor approximation, force capability with inverse model |
| 8 | 488-545 | Inverse model capability (cont.) [Figs. 11-12], Experimental validation (Sec. V) begins: setup, bead, grid scan |
| 9 | 546-620 | Validation: Langevin eq. (11), steady-state currents [Fig. 14], forces [Fig. 15], k_I_hat = 0.53 pN, Conclusion (Sec. VI) |
| 10 | 621-670 | References [1]-[26], Author biographies |

## Notes for Our ANSYS Simulation

### What we directly use from this paper:
1. **Geometry**: pole tip radius (40 um), rho (594 um), triangle side (840 um), layer spacing (508 um), foil thickness (178 um)
2. **Materials**: Ni-Fe-Mo alloy poles (B_sat ~2.1 T), cold-rolled steel yoke
3. **Coils**: 50 turns, AWG #24 (0.51 mm diameter)
4. **Configuration**: hexapole in two layers, 3 poles per layer at 120 deg spacing
5. **Pole numbering**: P1-P6 as labeled in Fig. 2(b) -- mapped to APDL coil numbers in MEMORY.md
6. **Linear superposition**: the force model assumes superposition of fields from individual coils, which justifies our approach of running 6 unit-excitation simulations and combining results in MATLAB

### What our ANSYS simulation provides that the paper does not:
1. Detailed 3-D magnetic field distribution (the paper only shows analytical point-charge approximation)
2. Exact B-field values at arbitrary locations (for comparison with lumped-parameter model)
3. Saturation effects in pole tips (the analytical model assumes linearity)
4. Verification of the K_I flux distribution matrix values (5/6 and 1/6)

### FEM details mentioned in the paper:
- The paper mentions using "finite element software" [18] to determine R_a = 2.8e9 A/Wb by comparing analytical and FEM fields
- No details of the FEM simulation are given in this paper -- they reference [18] (the quadrupole paper)
- Our ANSYS simulation essentially performs the same FEM analysis but for the hexapole configuration

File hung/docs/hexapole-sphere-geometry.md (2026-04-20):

# Hung Hexapole — Sphere Geometry Framework

## Pole 編號與配對

**上層 poles:** P2, P4, P5
**下層 poles:** P1, P3, P6

| Pair | Lower Pole | Upper Pole |
|---|---|---|
| I | P1 | P2 |
| II | P3 | P4 |
| III  | P6 | P5 |

## 座標系

| 座標系 | 符號 | 顏色 | 說明 |
|---|---|---|---|
| Assembly | (x_a, y_a, z_a) | 藍 | CAD/ANSYS 座標系 |
| Magnetic | (x_m, y_m, z_m) | 紅 | 軸沿 3 對 pair 方向，正交 |

## 球面幾何條件

球心 = working point (WP)，6 個 tip 在球面上。

| # | 條件 | 效果 |
|---|---|---|
| 1 | 每組 pair 連線過球心 | L_i = -U_i（對徑點） |
| 2 | 上層 3 tip 共平面，下層 3 tip 共平面 | 上下兩平行平面，對稱於球心 |
| 3 | 球半徑 R = 0.5 mm | 每個 tip 到 WP 距離 = 0.5 mm |
| 4 | 方位角等距 120° | 3 對 pair 在水平投影上均勻分布 |

## 數學框架

### 座標系設定

z 軸垂直於上下平面（從下層指向上層），球心在原點。

### 參數化

上層 tip 位於球面與上層平面的交圓上：

```
圓半徑：r = R sin(θ)
平面高度：h = R cos(θ)
```

θ = 球面極角（z 軸到 tip 方向的夾角），α = 90° - θ = 仰角（水平面到 tip 的仰角）。

### 6 個 tip 座標

方位角 φ_1 = 0°, φ_2 = 120°, φ_3 = 240°（可整體旋轉）。

**上層：**

```
U_i = ( r cos(φ_i),  r sin(φ_i),  h )    i = 1, 2, 3
```

**下層（對徑）：**

```
L_i = ( -r cos(φ_i), -r sin(φ_i), -h )   i = 1, 2, 3
```

其中 r² + h² = R²。

### 自由度

條件 1-4 後剩餘 **1 個自由度**：θ（或等價地 h）。

| θ | α (仰角) | h (mm) | r (mm) | 特性 |
|---|---|---|---|---|
| 小 | 大 | 大 | 小 | 上下平面遠離赤道，水平圓小 |
| 54.74° | **35.26°** | 0.2887 | 0.4082 | **Magic angle** |
| 大 | 小 | 小 | 大 | 上下平面靠近赤道，水平圓大 |

### Pair 方向向量

第 i 對 pair 的方向向量（U_i → L_i 或反向）：

```
d_i = U_i - L_i = ( 2r cos(φ_i), 2r sin(φ_i), 2h )
```

歸一化後：

```
d_hat_i = ( sin(θ) cos(φ_i), sin(θ) sin(φ_i), cos(θ) )
```

## 正交條件 → 固定 θ

d_hat_i · d_hat_j = 0 要求：

```
sin^2(θ) cos(φ_i - φ_j) + cos^2(θ) = 0
```

φ 間距 120° → cos(120°) = -1/2，代入得：

```
1 - 3cos^2(θ)/2 = 0  →  cos^2(θ) = 2/3  →  θ = 54.74°
```

α = 90° - 54.74° = **35.26° (magic angle)**

### MATLAB 驗證

```
Pair 1 vs 2: 90.00° ✓
Pair 1 vs 3: 90.00° ✓
Pair 2 vs 3: 90.00° ✓
Tip-to-tip: 1.000 mm ✓
```

---

## Pole 擺放

### 傾斜角

| 層 | Poles | 傾斜角 | 方向 |
|----|---|---|---|
| 上層 | P2, P4, P5 | 35° | 從 tip 沿軸往上往外延伸至 block |
| 下層 | P1, P3, P6 | 5.71° | 從 tip 沿軸往下往外延伸至 block |

### Pole 尺寸 (from Mag_Pole_Bottom.STEP)

| 參數 | 值 | 說明 |
|---|-----|---|
| 圓柱半徑 | 3.175 mm | Diameter 6.35mm |
| 錐段長度 | 15.875 mm | semi-angle 11.31° |
| 圓柱段長度 | 27.125 mm | 全圓 15mm + D型 12.125mm |
| 總長 | 43 mm | |
| 削平 | tip 起 28mm | 通過軸心的平面，去下半，flat face 朝上 |
| Tip | 尖錐頂點 | STEP 無 fillet |

### Tip 座標 (mm, magic angle)

| Pole | Type | Azimuth | Tip (x, y, z) mm |
|---|---|---|---|
| P1 | lower | 0° | (+0.4082, 0, -0.2887) |
| P2 | upper | 180° | (-0.4082, 0, +0.2887) |
| P3 | lower | 120° | (-0.2041, +0.3536, -0.2887) |
| P4 | upper | 300° | (+0.2041, -0.3536, +0.2887) |
| P5 | upper | 60° | (+0.2041, +0.3536, +0.2887) |
| P6 | lower | 240° | (-0.2041, -0.3536, -0.2887) |

> 座標與 APDL 程式碼一致：P1 在 +X 方向（azim=0°），upper 在 +Z，lower 在 -Z。

### APDL 模型

腳本：`hung/apdl/variants/MT_Hung_SphereModel.txt`
圖檔：`hung/figures/hexapole_sphere_6poles.png`

---

## 座標系轉換

**Assembly 座標系 = Measured 座標系**，不需要額外轉換。

| ANSYS 軸 | 方向 | 對應 pole |
|---|---|---|
| +X | P1 (0°) | Pair I 正方向 |
| +Y | P5 投影 (60°) | |
| +Z | 垂直向上 | upper tip 側 |

SolidWorks 開 IGES 後方向直接對應。

## 機構約束

| 參數 | 值 | 來源 |
|---|-----|---|
| TILT_UP | 35° | STEP 實測（upper pole 相對水平向上傾斜） |
| TILT_DN | 5.71° | STEP 實測（lower pole 相對水平向下傾斜） |
| TILT_UP + TILT_DN | 40.71° | 不滿足 70.53° 正交條件，需 pole 長度微調補償 |

正交條件要求 TILT_UP + TILT_DN = 70.53°（= 2 × magic angle）。
Hung 實際 40.71° < 70.53°，透過 pole 長度微調（見 `pole-geometry.md`）達到正交。

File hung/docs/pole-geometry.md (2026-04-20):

# Hung Hexapole — Pole Geometry

## Pole 編號與配對

**下層 poles:** 1, 3, 6
**上層 poles:** 2, 4, 5

| Pair | Lower Pole | Upper Pole |
|---|---|---|
| I | 1 | 2 |
| II | 3 | 4 |
| III | 6 | 5 |

## Pole 傾斜角度（STEP 實測）

### Hung

| Group | Poles | Tilt from Horizontal | Direction |
|---|---|---|---|
| Upper | 2, 4, 5 | **35°** | 向下傾斜（tip 在 block 下方） |
| Lower | 1, 3, 6 | **5.71°** | 向上傾斜（tip 在 block 上方） |

```
        Block (上, 外)
            \
             \  35° from horizontal
              \_________ 水平面
               \
                Tip (下, 內)          ← upper pole (2, 4, 5)

                Tip (上, 內)          ← lower pole (1, 3, 6)
               /  5.71°
              /_________ 水平面
             /
        Block (下, 外)
```

上下層 tip 從兩側匯聚到 working point。

**Source:** STEP 實測 `hung/step_for_fem/組合件1-7.STEP`

### Long2016

| Group | Poles | Tilt from Horizontal | Direction |
|---|---|---|---|
| Lower 3 | P1(0°), P3(120°), P6(240°) | **0°** (水平) | 完全水平 |
| Upper 3 | P5(60°), P2(180°), P4(300°) | **35°** | 向下傾斜（tip 在 block 下方） |

> 上層 35° 為 STEP 實測值（APDL 參數化模型計算為 36.6°，有 ~1.6° 差異）

```
        Block (上, 外)
            \
             \  35° from horizontal
              \_________ 水平面
               \
                Tip (下, 內)

    ─────────────────────── lower pole level
    Block (外) ────────── Tip (內)   ← 完全水平 (0°)
```

**Source:** STEP 實測 `01Long Fei Tweezer/01CAD Model/hall sensor assembly and Supporter Structure (2014-10-9)/ASSEM_The_Whole_Setup.STEP`

### Comparison

| | Long2016 | Hung |
|--|---|---|
| Upper tilt | 35° 向下 | 35° 向下 |
| Lower tilt | 0° (水平) | 5.71° **向上** |

上層角度相同（35°），下層 Hung 比 Long 多了 5.71° 向上傾斜。

---

## Tip Apex 位置（from Hexapole_Assembly_FEM.STEP）

| Pole | Type | Apex (mm) |
|---|---|---|
| 1 | lower | (-41.613, -82.923, -18.607) |
| 2 | lower | (-41.304, -83.321, -18.841) |
| 3 | lower | (-41.865, -83.276, -18.731) |
| 4 | upper | (-41.864, -82.940, -18.105) |
| 5 | upper | (-41.274, -82.883, -18.027) |
| 6 | upper | (-41.619, -83.654, -17.925) |

Hex center: (-42.21, -83.10) mm
全部 6 個 tip 匯聚於 hex center 附近（r < 1mm）。

---

## Pair Tip-to-Tip 連線夾角

### 連線方向

| Pair | 連線 | Direction (normalized) |
|---|---|---|
| I | Pole 1 → Pole 2 | (0.309, -0.398, -0.234) |
| II | Pole 3 → Pole 4 | (0.001, 0.336, 0.626) |
| III | Pole 6 → Pole 5 | (0.345, 0.771, -0.102) |

### 3D 夾角

| Pair 組合 | 銳角 | 鈍角 |
|---|---|---|
| I(1↔2) vs II(3↔4) | 77.0° | 103.0° |
| I(1↔2) vs III(6↔5) | 79.0° | **101.0°** |
| II(3↔4) vs III(6↔5) | 70.3° | 109.7° |

**三對 pole pair 的 tip-to-tip 連線在 3D 空間中不正交（≠90°）。**

鈍角範圍：101° ~ 110°，偏離正交 11° ~ 20°。

### 實測驗證

Pair I ↔ III 鈍角：
- 計算值：101.0°
- STEP 實測值：**100.98°** ✓

---

## 設計約束條件

| # | 約束 | 說明 |
|---|---|---|
| 1 | **3 對 pole pair 的 tip-to-tip 連線互相正交** | 3 條連線在 3D 空間中兩兩夾 90° |
| 2 | **每對 tip-to-tip 直線距離 = 1 mm** | opposing pair 的兩個 tip 端點間距 1 mm |

---

## Magic Angle 正交條件推導

### 座標系

- 原點 O：working point（6 tip 匯聚處）
- Z 軸：垂直向上
- XY 平面：水平面
- alpha：pair 軸與水平面的仰角
- phi：XY 平面上的方位角

### 設定

3 對 pair 軸以 120° 方位角排列，每對與水平面夾角都是 alpha。方向向量：

```
v1 = (cos(alpha)cos(phi1),  cos(alpha)sin(phi1),  sin(alpha))
v2 = (cos(alpha)cos(phi2),  cos(alpha)sin(phi2),  sin(alpha))
v3 = (cos(alpha)cos(phi3),  cos(alpha)sin(phi3),  sin(alpha))
```

其中 phi2 = phi1 + 120°，phi3 = phi1 + 240°。

### 正交條件

v1 · v2 = 0：

```
v1 · v2 = cos^2(alpha) × [cos(phi1)cos(phi2) + sin(phi1)sin(phi2)] + sin^2(alpha)
```

中括號項 = cos(phi2 - phi1) = cos(120°) = -1/2，所以：

```
v1 · v2 = cos^2(alpha) × (-1/2) + sin^2(alpha)
```

代入 sin^2(alpha) = 1 - cos^2(alpha)：

```
= -cos^2(alpha)/2 + 1 - cos^2(alpha)
= 1 - 3cos^2(alpha)/2
```

令 = 0：

```
1 - 3cos^2(alpha)/2 = 0
3cos^2(alpha)/2 = 1
cos^2(alpha) = 2/3
alpha = arccos(sqrt(2/3)) = 35.26°
```

### 結論

當 3 對 pair 以 **120° 等距方位排列**且**傾斜角相同**時，alpha = **35.26°（magic angle）**是唯一讓 3 軸正交的角度。

Long2016 設計選擇 ~35° 即為逼近此 magic angle。

### 正交時的 tip-to-tip 分量（d = 1mm 端到端距離）

```
水平分量 h  = d × cos(35.26°) = d × sqrt(2/3) = 0.8165 mm
垂直分量 dz = d × sin(35.26°) = d / sqrt(3)   = 0.5774 mm
```

---

## 維持正交的上下層角度組合

### 公式

正交條件要求 pair 的 tip-to-tip 向量滿足 dz/dh = 1/√2。

當上層傾斜 a_upper（向下）、下層傾斜 a_lower（向上）時：

```
(sin(a_upper) + sin(a_lower)) / (cos(a_upper) + cos(a_lower)) = 1/√2
```

簡化為：

```
a_lower = 70.53° - a_upper
```

（即上下層角度之和 = 70.53° = 2 × 35.26°）

### 可行組合

| 方案 | Upper (↓) | Lower (↑) | 合計 | 正交? | 備註 |
|---|---|---|---|---|---|
| A 完美對稱 | 35.26° | 35.27° | 70.53° | ✓ | 最理想（場對稱） |
| B | 35° | 35.53° | 70.53° | ✓ | 接近對稱 |
| C | 40° | 30.53° | 70.53° | ✓ | |
| D | 30° | 40.53° | 70.53° | ✓ | |
| E | 45° | 25.53° | 70.53° | ✓ | |
| **F Long2016** | **35°** | **0°** | **35°** | **✗** | pair tilt=17.5°≠35.26° |
| **G Hung 現況** | **35°** | **5.71°** | **40.71°** | **✗** | pair tilt≠35.26° |

### 重要發現

**Long2016 的 upper=35° + lower=0° 並不滿足正交條件！**

正交需要 a_upper + a_lower = 70.53°，但 Long2016 只有 35° + 0° = 35°。

Long2016 之所以「近似正交」是因為 R_norm_xy 和 R_norm_z 的設定（tip 位置偏移）另外補償了角度不足。但嚴格來說，pair 軸傾斜只有 17.5°，不是 magic angle 35.26°。

### 對 Hung 的建議

若要從**角度**達到正交（不依賴 tip 位置微調）：
- 維持 upper = 35° → lower 需要 **35.53°** 向上
- 或 upper = 40° → lower = **30.53°** 向上
- 最簡單：兩層都設 **35.26°**（完美對稱）

---

## Pole 長度調整（正交 + 1mm 最佳化結果）

### 方法
保持 pole 傾斜角不變（upper 35°, lower 5.71°），僅調整每根 pole 長度（≤ 1.3% of 43mm = 0.54mm），使 3 對 pair 的 tip-to-tip 連線達到正交 + 1mm。

### 調整量

| STEP Pole | Type | dl (mm) | 動作 | 佔 pole 長度 |
|---|---|---|---|---|
| 1 | lower | -0.074 | 縮短 | 0.17% |
| 2 | lower | -0.542 | 縮短 | 1.26% |
| 3 | lower | -0.437 | 縮短 | 1.02% |
| 4 | upper | +0.450 | 加長 | 1.05% |
| 5 | upper | +0.367 | 加長 | 0.85% |
| 6 | upper | +0.060 | 加長 | 0.14% |

### 調整後 tip 位置

| Pole | Type | New Apex (mm) |
|---|---|---|
| 1 | lower | (-41.6129, -82.8493, -18.6144) |
| 2 | lower | (-40.8377, -83.5914, -18.8949) |
| 3 | lower | (-42.2417, -83.4925, -18.7745) |
| 4 | upper | (-41.5447, -83.1250, -18.3634) |
| 5 | upper | (-41.5346, -83.0326, -18.2374) |
| 6 | upper | (-41.6189, -83.6049, -17.9594) |

### 驗證（MATLAB 計算）

```
Pair A (1↔6): d = 1.000000 mm ✓
Pair B (2↔4): d = 1.000000 mm ✓
Pair C (3↔5): d = 1.000000 mm ✓

Angle A-B: 90.0000° ✓
Angle A-C: 90.0000° ✓
Angle B-C: 90.0000° ✓
```

### ANSYS 驗證（已完成）

模型建構：`hung/apdl/variants/MT_Hung_SphereModel.txt` → `Hung_SphereModel.iges`
SolidWorks 量測確認：

```
6 tips on R=0.5mm sphere: ✓
Tip-to-tip (Pair I,  P1↔P2): 1.000 mm ✓
Tip-to-tip (Pair II, P3↔P4): 1.000 mm ✓
Tip-to-tip (Pair III,P6↔P5): 1.000 mm ✓

Pair I  vs II:  90.00° ✓
Pair I  vs III: 90.00° ✓
Pair II vs III: 90.00° ✓
```

ANSYS 模擬比較（Coil1 激發, 70 A-turns）：

| 量測位置 | Hung | Long2016 |
|---|---|---|
| P1 tip (R=0.5mm) | 333 mT | 350 mT |
| WP 幾何中心 | 9.3 mT | 8.7 mT |

兩者在等效位置的 B-field 幾乎相同。

---

## Source
- Hung STEP: `hung/step_for_fem/Hexapole_Assembly_FEM.STEP`, `hung/step_for_fem/組合件1-7.STEP`
- Long2016 STEP: `01Long Fei Tweezer/01CAD Model/hall sensor assembly and Supporter Structure (2014-10-9)/ASSEM_The_Whole_Setup.STEP`
- Cone apex 提取方法：semi-angle matching (0.1974 rad = 11.31°)

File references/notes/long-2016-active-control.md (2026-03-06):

# Actively Controlled Hexapole Electromagnetic Actuating System Enabling 3-D Force Manipulation in Aqueous Solutions

## Bibliographic Info

| Field | Value |
|---|---|
| Authors | Fei Long, Daisuke Matsuura, Chia-Hsiang Menq |
| Year | 2016 (published online Nov 25, 2015; print June 2016) |
| Type | Journal paper |
| Source | IEEE/ASME Transactions on Mechatronics, Vol. 21, No. 3, pp. 1540-1551 |
| DOI | 10.1109/TMECH.2015.2503274 |
| Funding | NSF CMMI Grant 1067962 and 1200017 |
| PDF file | `pdfs/Actively_Controlled_Hexapole_Electromagnetic_Actuating_System_Enabling_3-D_Force_Manipulation_in_Aqueous_Solutions.pdf` |
| Total pages | 12 |

## Relevance to This Project

This is the **journal paper version** of the hexapole actuator described in Fei Long's dissertation (Ch. 2-3). It presents the same device we simulate in ANSYS: 1018 steel poles, 40 um tip radius, 70-turn coils, 500 um workspace. It contains the FEM-calibrated K_I matrix (K^FEM_I), the experimentally calibrated K_hat_I, force calibration results, and optimal inverse model. The ANSYS FEM mesh shown in Fig. 2(b) is the direct reference for our simulation.

**Tags:** geometry, materials, fem-simulation, calibration, force-model, inverse-model, superposition, coil-design, optimal-control

## Key Contributions

- New hexapole design using 1018 steel (>2T saturation) replacing thin permalloy film (0.9T), yielding 4x force gain increase
- FEM validation of magnetic charge model: workspace radius rho = 900 um, air reluctance R_a = 6.3e8 A/Wb, error <1%
- FEM-calibrated K_I^FEM matrix showing upper/lower pole asymmetry (diag: 0.83 lower vs 1.04 upper)
- Experimentally calibrated K_hat_I from measurement coils (diag: 0.60-0.63 lower vs 0.90-0.93 upper)
- Optimal inverse model minimizing ||I||^2, orientation-dependent constraints replace constant constraints
- Force generation: ~600 pN (optimal) vs ~100 pN (constant constraints) with 3A max current
- Linear range confirmed up to 3A (no saturation for P2 or P3)

## Detailed Notes by Section

### I. Introduction (pp. 1540-1541, lines 1-75)

Compares AFM, optical tweezers, and magnetic tweezers. Previous magnetic actuators used thin permalloy film poles (100 um thick, 0.9T saturation). Limitations: required custom sample chambers, small cross-section yielded low flux, constant-constraint inverse model limited force. This paper addresses all three with new design and optimal inverse.

Key references: [1] = quadrupole tweezers (Zhang, Huang, Menq 2010), [2] = hexapole actuator design (Zhang and Menq 2011), [40] = 3D visual servo (Zhang, Long, Menq 2013).

### II-A. Design, Synthesis, and Fabrication (pp. 1541-1542, lines 103-161)

Three pairs of poles on three orthogonal axes (actuation coordinate), rigid body rotation applied so tips lie on two horizontal planes.

- Lower poles: P1, P3, P6 — fixed under culture dish, milled flat
- Upper poles: P2, P4, P5 — tips sink into medium above dish
- Opposite pairs: P2<->P1 (+x), P4<->P3 (+y), P6<->P5 (+z) in actuation coordinate
- Each pole has actuation coil (flux generation) + measurement coil (flux measurement)

**Fig. 2(a):** Fabricated prototype on inverted microscope — shows pole labeling and coordinate system.
**Fig. 2(b):** CAD model and meshing of hexapole actuator — **our ANSYS FEM mesh reference**.

### II-B. Finite Element Analysis (pp. 1542-1543, lines 157-207)

- CAD model built and meshed using **ANSYS environment** for FEM calculation (Fig. 2b)
- 1A current applied to coil 1
- Fig. 3(a): Top view vector plot — field forms closed loop guided by poles + yoke
- Fig. 3(b): B vectors in 100 um cube at workspace center — all point to pole 1 tip
- Fig. 3(c): Near pole 1 tip — vectors strongly converge, validates point charge assumption
- Flux density at workspace center is **2x** that of previous thin-foil design
- Fig. 4: Contour plot of |B| in horizontal and vertical planes (in Gauss)

### II-C. Hexapole Magnetic Field Model (pp. 1543, lines 209-263)

**Eq. (1): Superposition field model**
B(p) = sum_{i=1}^{6} k_m * (q_i / r_i^2) * u_i(p)

**Eq. (2): Charge-current relation (Hopkinson's law)**
Q = Phi/mu_0 = (N_c / (mu_0 * R_a)) * K_I * I

Best-fit parameters from FEM:
- Workspace radius (charge location): **rho = 900 um**
- Air reluctance: **R_a = 6.3 x 10^8 A/Wb**
- Fitting error: mostly <1% of flux density norm (Fig. 5b)

**K_I^FEM matrix (Eq. 3) — from FEM fitting, normalized so K_I(1,1) = 5/6:**

| | P1 | P2 | P3 | P4 | P5 | P6 |
|---|---|---|---|---|---|---|
| P1 | **0.8333** | -0.2312 | -0.1935 | -0.1375 | -0.1375 | -0.1935 |
| P2 | -0.4042 | **1.0388** | -0.2481 | -0.1012 | -0.1012 | -0.2481 |
| P3 | -0.1935 | -0.1375 | **0.8333** | -0.2312 | -0.1375 | -0.1935 |
| P4 | -0.2481 | -0.1012 | -0.4042 | **1.0388** | -0.1012 | -0.2481 |
| P5 | -0.2481 | -0.1012 | -0.2481 | -0.1012 | **1.0388** | -0.4042 |
| P6 | -0.1935 | -0.1375 | -0.1935 | -0.1375 | -0.2312 | **0.8333** |

Key: Lower poles (P1, P3, P6) diag = 0.83; Upper poles (P2, P4, P5) diag = 1.04.

### III-A. Hexapole Magnetic Force Model (pp. 1544, lines 269-314)

**Eq. (4): Quadratic force model**
F_i(p_hat, I) = g_I * I^T * K_I^T * L_i(p_hat) * K_I * I, i = x, y, z

**Eq. (5): Maximum force (force generation capability)**
F_max = g_I * I_max^2 = 3V * k_m^2 * [(mu - mu_0) / (2*mu_0*rho^5*(mu + 2*mu_0))] * (N_c / (mu_0 * R_a))^2 * I_max^2

**Eq. (6): Dimensionless force**
F_hat_i = I_hat^T * K_I^T * L_i * K_I * I_hat

### III-B. Inverse Model — Constant Constraints (pp. 1544, lines 316-334)

Constraints: I_hat_1 + I_hat_2 = c_x, I_hat_3 + I_hat_4 = c_y, I_hat_5 + I_hat_6 = c_z

**Eq. (7): Force at center (linear in effective current)**
F_hat_c = 2 * A * delta_I_hat

**Eq. (8): Actuation matrix**
A = diag[(2c_x + c_y + c_z), (c_x + 2c_y + c_z), (c_x + c_y + 2c_z)]

**Eqs. (9-10): Inverse model at center**
[I_hat_1, I_hat_3, I_hat_5] = (1/2)*b + (1/4)*A^{-1}*F_hat_c
[I_hat_2, I_hat_4, I_hat_6] = (1/2)*b - (1/4)*A^{-1}*F_hat_c

Problem: constant bias b causes unnecessarily large currents; force scales linearly (not quadratically) with current.

### III-C. Optimal Inverse Model (pp. 1544-1545, lines 336-396)

**Eq. (11): Optimal current allocation**
I_hat_opt(F_hat_d, p_hat) = ||F_hat_d||^{1/2} * I_opt(r_hat(phi, theta), p_hat)

**Eq. (12): Norm decomposition**
||I_hat||^2 = (1/2)*||delta_I_hat||^2 + c_x^2 + c_y^2 + c_z^2

**Eq. (13): Objective function**
J(c_x, c_y, c_z; phi, theta) = (1/2)*(c_x^2 + c_y^2 + c_z^2) + (1/8)*||A^{-1}*r_hat||^2

Minimizing J yields orientation-dependent optimal constraints c_x(phi,theta), c_y(phi,theta), c_z(phi,theta).

Fig. 7: Optimal constraints vs constant constraints — optimal are much smaller.
Fig. 8: Optimal currents vs constant — each of 6 inputs significantly smaller.

### IV. Stabilization (pp. 1545-1546, lines 397-438)

**Eq. (14): Bead dynamics (Langevin equation)**
m*P_ddot + gamma*P_dot = F_MT(t) + F_T(t)

Inertia negligible -> first-order system.

Fig. 9: Feedback control block diagram (P controller + inverse model).
Fig. 10: Six input currents — optimal allocation yields smaller currents.
Fig. 11: Stabilization results:
- Optimal: std dev = (52.36, 64.51, 28.62) nm
- Constant constraints: std dev = (107.32, 69.95, 28.62) nm

### V. Calibration and Validation (pp. 1546-1548, lines 441-588)

**Flux distribution matrix calibration:**
- Method: electromagnetic induction (Faraday's law) using measurement coils
- E(t) = -N_m * dPhi(t)/dt
- Sinusoidal current to each actuation coil, measure 6 induction voltages (Fig. 12)

**Calibrated K_hat_I matrix (Eq. 15):**

| | P1 | P2 | P3 | P4 | P5 | P6 |
|---|---|---|---|---|---|---|
| P1 | **0.6022** | -0.0124 | -0.0285 | -0.1507 | -0.1668 | -0.0229 |
| P2 | -0.0103 | **0.9322** | -0.1740 | -0.0787 | -0.0680 | -0.1780 |
| P3 | -0.0294 | -0.1655 | **0.6291** | -0.0121 | -0.1458 | -0.0319 |
| P4 | -0.1540 | -0.0712 | -0.0112 | **0.9040** | -0.0746 | -0.1501 |
| P5 | -0.1805 | -0.0712 | -0.1521 | -0.0769 | **0.9026** | -0.0095 |
| P6 | -0.0235 | -0.1726 | -0.0331 | -0.1506 | -0.0123 | **0.6122** |

Lower poles (P1, P3, P6) diag = 0.60-0.63; Upper poles (P2, P4, P5) diag = 0.90-0.93.
Cause: lower poles milled flat -> material removed -> reduced actuation gain.

**Force calibration (Eq. 16):**
- Bead steered along 12 linear trajectories in glycerol at 6.5 um/s
- Viscous force = gamma * v_p = 55 pN (gamma = 8.5e-6 N.s/m)
- N = 14,412 samples, minimize J(g_I, c) = sum ||F_v - F_model||^2
- Degaussed between trajectories

**Three calibration options:**

| Option | K_I used | g_I (pN) | Avg error (pN) |
|---|---|---|---|
| 1. Nominal K_I | Theoretical (5/6, -1/6) | [5.37, 6.82, 6.93] | 12.42 |
| 2. Measured K_hat_I | From induction (Eq. 15) | [9.08, 9.64, 8.39] | 10.04 |
| 3. Modified K_tilde_I | Lower rows x 1.2 | [7.56, 8.55, 7.62] | 8.25 |

Thermal force contributes ~4 pN to avg error. Actual modeling error much smaller than 110 pN calibration range.

**K_tilde_I^n matrix (Eq. 17) — best model, normalized so (1,1) = 5/6:**

| | P1 | P2 | P3 | P4 | P5 | P6 |
|---|---|---|---|---|---|---|
| P1 | **0.8333** | -0.0171 | -0.0394 | -0.2085 | -0.2308 | -0.0317 |
| P2 | -0.0119 | **1.0749** | -0.2006 | -0.0908 | -0.0784 | -0.2052 |
| P3 | -0.0407 | -0.2291 | **0.8704** | -0.0167 | -0.2018 | -0.0442 |
| P4 | -0.1775 | -0.0913 | -0.0130 | **1.0423** | -0.0860 | -0.1730 |
| P5 | -0.2081 | -0.0821 | -0.1754 | -0.0887 | **1.0407** | -0.0109 |
| P6 | -0.0326 | -0.2388 | -0.0458 | -0.2085 | -0.0171 | **0.8471** |

Diagonal terms agree well with K_I^FEM; off-diagonal terms differ (FEM uses flux density directly; force calibration uses force; nominal material properties in FEM).

### VI. Force Generation Capability (pp. 1548-1549, lines 591-642)

- Linear range test: P2 and P3 tested up to 3A with Hall sensor — no saturation (Fig. 19)
- F_max = k_I * I_max^2 — new design yields **4x force gain** over previous thin-foil design
- Fig. 20: Force envelopes (nominal models, spatially symmetric):
  - Old design + constant constraints (blue): smallest
  - New design + constant constraints (red): ~4x larger
  - New design + optimal allocation (gray): ~6x larger than old
- Fig. 21: Force envelopes (calibrated models):
  - Lower pole material removal causes asymmetry
  - Significant improvement remains evident

### VII. Conclusion (pp. 1549, lines 616-642)

Future work identified:
1. Extend optimal inverse to entire workspace (not just center)
2. Shorten feedback delay (high-speed vision tracking)
3. Address hysteresis through modeling or real-time sensing

## Equations and Parameters We Use

### Device Parameters

| Parameter | Value | Page |
|---|---|---|
| Pole material | 1018 steel (0.18% C) | p.1542 |
| Saturation limit | >2T | p.1542 |
| Pole diameter | ~6 mm | p.1542 |
| Upper pole length | ~45 mm | p.1542 |
| Lower pole length | ~42 mm (milled flat) | p.1542 |
| Pole tip radius | 40 um | p.1542 |
| Workspace radius (nominal) | 500 um | p.1542 |
| Workspace radius (charge model, FEM fit) | 900 um | p.1543 |
| Air reluctance (FEM fit) | 6.3e8 A/Wb | p.1543 |
| Coil turns | 70 | p.1542 |
| Max current (linear range) | 3 A | p.1549 |
| Bead | Dynabead M-450 Epoxy, 4.5 um | p.1542 |
| Drag coeff (glycerol) | 8.5e-6 N.s/m | p.1547 |
| Cover glass thickness | ~100 um | p.1541 |
| k_m = mu_0/(4*pi) | 1.0e-7 N/A^2 | p.1543 |

### Key Equations

| Eq. | Expression | Description |
|-----|---|---|
| (1) | B = sum k_m*q_i/r_i^2 * u_i | Hexapole field (superposition) |
| (2) | Q = (N_c/(mu_0*R_a)) * K_I * I | Charge-current relation |
| (3) | K_I^FEM (6x6 matrix) | FEM-calibrated flux distribution |
| (4) | F_i = g_I * I^T * K_I^T * L_i * K_I * I | Quadratic force model |
| (5) | F_max = g_I * I_max^2 | Force generation capability |
| (6) | F_hat_i = I_hat^T * K_I^T * L_i * K_I * I_hat | Dimensionless force |
| (7) | F_hat_c = 2*A*delta_I_hat | Center force (constant constraints) |
| (11) | I_opt = ||F_d||^{1/2} * I_unit(phi,theta) | Optimal inverse model |
| (15) | K_hat_I (6x6 matrix) | Experimentally calibrated K_I |
| (17) | K_tilde_I^n (6x6 matrix) | Best-fit K_I (lower x 1.2) |

## Figures Worth Revisiting

| Figure | Page | Description | Why revisit |
|---|---|---|---|
| Fig. 1 | p.1541 | (a) CAD of motion stage + lower poles; (b) yoke ring + upper poles | Geometry reference |
| Fig. 2 | p.1542 | (a) Prototype with pole labels; (b) **CAD model + FEM mesh** | **Critical** — our ANSYS mesh reference |
| Fig. 3 | p.1543 | (a) Top view B vectors; (b) workspace center; (c) near pole 1 tip | Validate our FEM results |
| Fig. 4 | p.1543 | Contour |B| horizontal + vertical planes (Gauss) | Compare with our contour plots |
| Fig. 5 | p.1543 | (a) FEM vs model vectors; (b) error norms <1% | Charge model validation |
| Fig. 19 | p.1549 | Linear range test P2 and P3 to 3A | **Critical** — no saturation at 3A |
| Fig. 20-21 | p.1549 | Force envelopes (nominal + calibrated) | Force capability comparison |

## Cross-References

- **[zhang-2011-actuator-design](zhang-2011-actuator-design.md)** (Ref. [2]): Previous hexapole design with thin permalloy film poles. This paper's new 1018 steel design replaces it.
- **[zhang-dissertation](zhang-dissertation.md)**: Quadrupole predecessor. Theoretical framework extended here to hexapole.
- **[long-2016-dissertation](long-2016-dissertation.md)**: This paper = Ch. 2-3 of the dissertation. Dissertation adds Hall sensors (Ch. 4) and dynamic force sensing (Ch. 5).

## Page Ranges for Claude

| Pages | Main Topic |
|---|---|
| 1-2 (lines 1-75) | Title, abstract, introduction |
| 2-3 (lines 76-161) | Design concept, fabrication, prototype |
| 3-4 (lines 157-263) | FEM analysis, field model, K_I^FEM matrix |
| 4-5 (lines 265-396) | Force model, constant/optimal inverse |
| 6-7 (lines 397-461) | Stabilization, control results |
| 7-9 (lines 441-588) | K_hat_I calibration, force calibration |
| 9-10 (lines 591-642) | Linear range, force capability |
| 10-12 (lines 642-773) | Conclusion, references, author bios |

## Relationship to Our ANSYS Simulation

**What we reproduce:** The exact CAD geometry (1018 steel, 40 um tip, 6 mm poles), FEM mesh (Fig. 2b), unit excitation (1A per coil), magnetic field distribution (Figs. 3-4).

**What our simulation adds:** Full 3D field data export, systematic verification of all 6 coils, potential re-fitting of K_I and rho.

**FEM details NOT specified in paper:** Element types, mesh size, boundary conditions, solver settings. Our APDL scripts use SOLID96 elements, SmartSize 5, DSP solver, MAG=0 BC.

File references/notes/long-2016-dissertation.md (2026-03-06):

# Three-Dimensional Motion Control and Dynamic Force Sensing of a Magnetically Propelled Micro Particle Using a Hexapole Magnetic Actuator

## Bibliographic Info

| Field | Value |
|---|---|
| Authors | Fei Long |
| Advisor | Chia-Hsiang Menq |
| Year | 2016 |
| Type | PhD Dissertation |
| Source | The Ohio State University, Department of Mechanical Engineering |
| DOI/URL | ProQuest 10145113 |
| PDF file | `pdfs/Fei Long_dissertation.pdf` |
| Total pages | 167 (xxiv + 141 numbered) |
| Committee | Chia-Hsiang Menq (advisor), Manoj Srinivasan, Rama Yedavalli, Vadim I. Utkin |

## Relevance to This Project

This is the **primary source** for the hexapole magnetic tweezers device we are simulating in ANSYS. It contains the complete device design (geometry, materials, coil specs), the FEM simulation methodology, the lumped-parameter magnetic force model, pole naming conventions, calibration procedures, and all key equations. Every aspect of our ANSYS simulation is based on this work.

**Tags:** geometry, materials, fem-simulation, calibration, force-model, inverse-model, pole-naming, coil-design, superposition, hall-sensor, dynamic-force-sensing

## Key Contributions

- Design and fabrication of a hexapole electromagnetic actuator using 1018 low-carbon steel (saturation >2T) with sharp-tipped poles (tip radius 40 um)
- Lumped-parameter magnetic force model: magnetic charge approximation validated by FEM, force is quadratic in current/flux
- Optimal inverse model minimizing 2-norm of currents (replaces constant-constraint approach), enabling real-time FPGA control at 1606 Hz
- Hall-sensor-based force model that bypasses hysteresis issues, achieving sub-pN accuracy
- Langevin-function model for nonlinear bead magnetization at high fields (>50 Gauss)
- Joint state-parameter estimator (Kalman filter) for simultaneous dynamic force sensing and drag coefficient estimation
- Calibrated flux distribution matrix K_I showing asymmetry between upper and lower poles
- Force generation capability: ~600 pN (optimal allocation) vs. ~100 pN (constant constraints) with 3A max current

## Detailed Notes by Section

### Abstract (pp. ii-iv, lines 82-196)

The dissertation develops a hexapole 3D magnetic actuator for use as a scanning probe system. Key capabilities: bead stabilization, trajectory tracking, accurate force modeling, and dynamic force sensing. The system is over-actuated (6 poles, 3 DOF force). Four main challenges: redundancy/coupling, instability, nonlinearity, position dependency. Hall sensors solve the hysteresis problem. Langevin function models nonlinear bead magnetization. Kalman filter enables dynamic force sensing.

### Chapter 1: Introduction (pp. 1-9, lines 973-1352)

#### 1.1 Background and Motivation (pp. 1-5)
- Magnetic tweezers advantages over optical tweezers: biocompatible, no heating, specific to magnetic particles
- Magnetic force field is inherently unstable (Earnshaw's theorem) -- feedback control required
- Previous designs used thin (~100 um) permalloy film poles -- limited flux and saturation (0.9T)
- Previous inverse model used constant constraints, resulting in excessive current and limited force

#### 1.2 Objectives and Specific Aims (pp. 5-8)
Four aims:
1. Hardware development, magnetic force modeling and calibration
2. Optimal inverse model and control (stabilization, Brownian motion control, trajectory tracking)
3. Hall sensor based 3D magnetic force modeling and feedback control
4. Dynamic force sensing and parameter estimation

#### 1.3 Dissertation Overview (pp. 8-9)
Chapter-by-chapter summary of the dissertation structure.

### Chapter 2: Design, Force Modeling and Inverse Modeling (pp. 10-42, lines 1353-2656)

**This is the most critical chapter for our simulation work.**

#### 2.2.1 Design, Synthesis, and Fabrication (pp. 12-15)

**Pole arrangement:**
- Three pairs of poles aligned on three orthogonal axes (actuation coordinate)
- Rigid body rotation applied so all tips lie on two parallel horizontal planes (upper and lower)
- Upper poles: P2, P4, P5; Lower poles: P1, P3, P6
- Opposite pairs: P2<->P1 (+x), P4<->P3 (+y), P6<->P5 (+z) in actuation coordinate

**Physical dimensions:**
- Pole material: **1018 steel** (low-carbon, 0.18% C), saturation limit **>2T**
- Pole diameter: **~6 mm**
- Upper poles length: **~45 mm**
- Lower poles length: **~42 mm** (milled flat to support culture dish)
- Pole tip radius: **40 um** (included in FEM model)
- Workspace radius (tip-to-center distance): **500 um** nominal (adjustable)
- Cover glass thickness between upper and lower planes: **~100 um**

**Coil specifications:**
- Actuation coils: **70 turns** each, wound around yoke protrusions
- Maximum current: **3 A** (linear range verified, no saturation at 3A)
- Power amplifiers: Micro Dynamics BTA-28V-6A, current mode, 10 kHz bandwidth
- DA converters: Measurement Computing PCI-DAS6032

**Magnetic bead:**
- Dynabead M-450 Epoxy, diameter **4.5 um**
- Superparamagnetic (aggregated gamma-Fe2O3 nanoparticles)
- Magnetic saturation: ms = 1.50e-12 Am^2 (nominal, recalculated as 1.40e-12)
- Linear magnetization range: up to ~50 Gauss

**Experimental setup:**
- Inverted microscope: Olympus IX 81, 60x dry objective
- CMOS camera: Mikrotron MC3010
- Image grabbing: Matrix Odyssey XCL
- Piezo positioner: PI P-721 PIFOC (lens driving for z calibration)
- Vibration isolation: Newport Smart Table + Herzan TS-150

#### 2.2.2 Finite Element Analysis of the Magnetic Field (pp. 15-17)

- CAD model built in **ANSYS** imitating real setup
- FEM analysis with 1A current applied to coil 1
- Magnetic field forms closed loop guided by poles + yoke
- Field vectors within 100 um cube at workspace center all point toward pole 1 tip
- Field vectors near tip strongly converge -- validates point charge assumption
- Flux density near workspace center is **2x** that of previous thin-foil design
- Fig.2.2(b): CAD model and meshing shown (important figure for our simulation)
- Fig.2.3: Vector plot of B field distribution, workspace center vectors, tip convergence
- Fig.2.4: Contour plot of |B| in horizontal and vertical planes (units: Gauss)

#### 2.2.3 Hexapole Magnetic Field Model (pp. 17-21)

**Coordinate systems:**
- Measurement coordinate: {O; x_m, y_m, z_m} -- aligned with microscope/camera
- Actuation coordinate: {O; x_a, y_a, z_a} -- aligned with pole pair axes
- Rotation matrix R_ma between the two frames needed for control

**Pole-current assignment (actuation coordinate):**
- Lower poles/charges: I1 (P1), I3 (P3), I6 (P6)
- Upper poles/charges: I2 (P2), I4 (P4), I5 (P5)

**Magnetic charge model (Eq. 2.1-2.3):**
- Each sharp tip behaves as a point magnetic charge: q_i = Phi_i / mu_0
- Field from charge i: B_i(p, b_i) = k_m * (q_i / r_i^2) * u_i, where k_m = mu_0/(4*pi) = 1.0e-7 N/A^2
- Total field: B(p, b) = (k_m / rho^2) * R_hat(p_hat, b) * Q (Eq. 2.3)
  - R_hat: 3x6 Charge-Bead Distribution Matrix
  - Q: 6x1 Charge Vector
  - rho: workspace radius (distance from charge to center)
  - b: 18-dimensional Bias Vector (charge locations may differ from tip locations)

**Flux distribution (Eq. 2.4):**
- Phi = K_I * [F1...F6]^T / R_a, where F_i = N_c * I_i (magnetomotive force)
- N_c = 70 (coil turns)
- R_a = lumped air reluctance from pole tip to workspace center
- K_I: 6x6 flux distribution matrix describing magnetic coupling among 6 poles
- Q = Phi/mu_0 = (N_c / (mu_0 * R_a)) * K_I * I

**Best-fit parameters from FEM:**
- Workspace radius rho = **900 um** (effective magnetic charge location, NOT the physical tip distance of 500 um)
- Air reluctance R_a = **6.3e8 A/Wb**
- Fitting error: mostly <1% of flux density norm (Fig. 2.6)

#### 2.3.1 General Magnetic Force Model (pp. 21-22)

**Gradient force on superparamagnetic particle (Eq. 2.5-2.6):**
- F = (1/2) * grad(m . B), where m = (3V/mu_0) * [(mu - mu_0)/(mu + 2*mu_0)] * B
- Force model in quadratic form: F_i(p_hat, Phi) = f_Phi * (1/mu_0^2) * Phi^T * L_i(p_hat) * Phi, i = x,y,z
- f_Q = magnetic charge force gain (depends on bead properties and geometry)
- f_Phi = f_Q * mu_0^2 = magnetic flux force gain
- L_x, L_y, L_z: 6x6 Charge-Bead Gradient Matrices (position-dependent)

#### 2.3.2 Current-Based Magnetic Force Model (pp. 22-24)

**Force model (Eq. 2.7):**
- F_i(p_hat, I) = g_I * I^T * K_I^T * L_i(p_hat) * K_I * I, i = x,y,z
- g_I = 3V*(mu - mu_0)*k_m^2 / (2*mu_0*(mu + 2*mu_0)*rho^5) * (N_c/(mu_0*R_a))^2

**Nominal flux distribution matrix K_I (Eq. 2.8):**

    K_I = [ 5/6  -1/6  -1/6  -1/6  -1/6  -1/6 ]
          [-1/6   5/6  -1/6  -1/6  -1/6  -1/6 ]
          [-1/6  -1/6   5/6  -1/6  -1/6  -1/6 ]
          [-1/6  -1/6  -1/6   5/6  -1/6  -1/6 ]
          [-1/6  -1/6  -1/6  -1/6   5/6  -1/6 ]
          [-1/6  -1/6  -1/6  -1/6  -1/6   5/6 ]

**Normalized force (Eq. 2.9-2.10):**
- F_N = g_I * I_max^2 (force generation capability metric)
- F_hat_i = I_hat^T * K_I^T * L_i * K_I * I_hat (dimensionless force field)

#### 2.3.3 Inverse Model Based on Constant Constraints (pp. 24-25)

- Constraints: I_hat_1 + I_hat_2 = c_x, I_hat_3 + I_hat_4 = c_y, I_hat_5 + I_hat_6 = c_z
- Effective input currents: delta_I_hat = [I_hat_1 - I_hat_2, I_hat_3 - I_hat_4, I_hat_5 - I_hat_6]
- At center: F_hat_c = 2*A * delta_I_hat, where A = diag[(2c_x+c_y+c_z), (c_x+2c_y+c_z), (c_x+c_y+2c_z)]
- Result: force increases linearly (not quadratically) with current -- severely limits force generation

#### 2.3.4 Optimal Inverse Model at Center (pp. 25-28)

- Express desired force in spherical coordinates: F_hat_d = |F_hat_d| * r_hat(theta, phi)
- Optimal solution: I_hat_opt = |F_hat_d|^(1/2) * I_opt_unit(theta, phi, p_hat) (Eq. 2.15)
- Minimize ||I_hat||^2 subject to force model constraint
- Orientation-dependent optimal constraints c_x(theta,phi), c_y(theta,phi), c_z(theta,phi) replace constant constraints
- Optimal currents are significantly smaller in absolute value (Fig. 2.9)

#### 2.4 Experimental Verification (pp. 28-31)

- Feedback control with constant-gain PI controller
- Total delay: tau_D = tau_a + tau_m + tau_ZOH
- Bead dynamics (Langevin equation): gamma * P_dot = F_MT + F_T (inertia negligible)
- Brownian motion with optimal allocation shows improved stabilization (Fig. 2.12)
- Optimal current allocation yields significantly smaller currents (Fig. 2.11)

#### 2.5 Calibration and Validation (pp. 31-38)

**Calibrated flux distribution matrix K_I_hat (Eq. 2.19):**

    K_I_hat = [ 0.6022  -0.0124  -0.0285  -0.1507  -0.1668  -0.0229 ]
              [-0.0103   0.9322  -0.1740  -0.0787  -0.0680  -0.1780 ]
              [-0.0294  -0.1655   0.6291  -0.0121  -0.1458  -0.0319 ]
              [-0.1540  -0.0712  -0.0112   0.9040  -0.0746  -0.1501 ]
              [-0.1805  -0.0712  -0.1521  -0.0769   0.9026  -0.0095 ]
              [-0.0235  -0.1726  -0.0331  -0.1506  -0.0123   0.6122 ]

**Key observation:** Diagonal entries for lower poles (P1: 0.60, P3: 0.63, P6: 0.61) are significantly smaller than upper poles (P2: 0.93, P4: 0.90, P5: 0.90). This is because material was removed from lower poles to form flat platform for culture dish.

**Force calibration procedure:**
- Steer bead along 12 linear trajectories in horizontal plane at constant speed in glycerol
- Viscous force = gamma * v_p serves as reference force (gamma calibrated as 8.5e-6 N.s/m)
- Speed: 6.5 um/s, yielding 55 pN viscous force
- Minimize: J(g_I, c) = sum |F_v(j) - F(p(j), I(j); g_I, K_I(c))|^2, N = 14412 samples

**Three calibration options and results:**
1. Nominal K_I: g_I = [5.37, 6.82, 6.93] pN, average error = 12.42 pN
2. Measured K_I_hat: g_I = [9.08, 9.64, 8.39] pN, average error = 10.04 pN
3. Modified K_I_hat (lower poles scaled by c=1.2): g_I = [7.56, 8.55, 7.62] pN, average error = 8.25 pN

Thermal force contributes ~4 pN to the average error. Actual modeling error is much smaller than the 110 pN calibration range.

#### 2.6 Force Generation Capability (pp. 38-41)

- Linear range verified up to 3A (no saturation observed for P2 or P3)
- New design: 4x increase in force gain over previous thin-foil design
- With optimal current allocation, force envelope is dramatically larger than constant constraints
- Force envelopes are spatially symmetric with nominal model; calibrated model shows asymmetry due to upper/lower pole differences

#### 2.7 Conclusion (pp. 41-42)

Summary and future directions: extend optimal inverse to entire workspace, shorten feedback delay, address hysteresis.

### Chapter 3: Optimal Inverse Model and Control (pp. 43-64, lines 2657-3486)

#### 3.2 Hardware: High Speed Control (pp. 44-46)

- FPGA-based system (DE2-115, Terasic) for real-time control
- Two TR4-230 FPGA boards for image processing
- SLD illumination (QPhotonics) for improved image sensitivity
- Visual sensing resolution: ~0.13 nm (x,y with 60x lens), sub-nm (z)
- CMOS camera: 8 um pixel size
- Sampling rate: **1606 Hz** (max for 512x512 image), higher possible with smaller images
- DA converters: DAC8814 EVM (Texas Instruments)
- Reference bead on coverslip for drift compensation

#### 3.3.1 Position-Dependent Inverse (Constant Constraints) (pp. 46-47)

- Taylor expansion around center: F_hat(p_hat, delta_I_hat) = J_deltaI * delta_I_hat + J_phat * p_hat (Eq. 3.1)
- Approximate inverse: delta_I_hat = J_deltaI^(-1) * F_hat_d - J_deltaI^(-1) * J_phat * p_hat (Eq. 3.2)
- Must apply rotation matrix R_ma between measurement and actuation coordinates

#### 3.3.2 Optimal Inverse Model in Entire Workspace (pp. 47-53)

- Lagrange multiplier optimization (Eq. 3.4): minimize ||I_hat||^2 subject to force model
- Nine parameters (6 currents + 3 multipliers), solved using MATLAB optimization toolbox
- Center solution serves as initial guess for positions away from center
- Computed in first octant (45x45x45 um cube), extends to 90x90x90 um full workspace
- **Least-square fitting** of inverse model (Eq. 3.6) outperforms Taylor expansion:
  - I_hat_opt_unit(theta, phi, P_hat)_i = P^T * C_LS(theta, phi)_i * P
  - P = [x, y, z, 1]^T augmented position vector
  - C_LS: 4x4 matrix from least-square fitting (different from Taylor coefficients)
  - Force error with LS fitting: almost always **<5%** across entire workspace
  - Interpolation used between discrete orientations where solutions are computed

#### 3.4 Active Feedback Control (pp. 53-60)

**Stabilization (3.4.1):**
- P controller: gamma * P_dot(t) = K_p * [P_d(t-tau_A) - P(t-tau_D)] + Delta_F(t) + F_T(t)
- Bead stabilized at 75 points (3 layers x 25 points), 10 um spacing
- Optimal inverse: smaller current, smaller Brownian motion std dev, smaller positioning error
- Steady-state error e|_DeltaF = 1/K_p (type 1 system)
- Nyquist stability: K_p < pi/(2*tau_D)

**Trajectory tracking (3.4.2):**
- Circular trajectories in xy, yz, xz planes at 5 um/s
- Optimal tracking error std: (57.82, 43.81, 42.01) nm vs. constant constraints: (123.10, 63.08, 109.83) nm

#### 3.5 High Speed vs. Low Speed Control (pp. 60-63)

- PSD analysis to calibrate K_p, gamma, tau_D
- 200 Hz (PC): tau_D = 12 ms (2.4 sampling intervals), gamma_x = 5.51e-8 N.s/m
- 1606 Hz (FPGA): tau_D = 2.9 ms, gamma_x = 3.71e-8, gamma_z = 6.43e-8 N.s/m
- Minimum Brownian std dev at 1606 Hz: (31.68, 30.65, 27.34) nm vs. 200 Hz: (51.97, 51.55, 36.32) nm
- Structure vibration peak at 71.37 Hz visible in PSD

#### 3.6 Conclusion (pp. 63-64)

Optimal inverse model solves redundancy + nonlinearity + position-dependency. FPGA high-speed control greatly reduces delay and Brownian fluctuation.

### Chapter 4: Hall Sensor Based Force Modeling (pp. 65-110, lines 3487-5207)

#### 4.2.1 Hall-Sensor-Based Force Model (pp. 66-68)

**Key idea:** Replace current-to-flux relationship (which suffers from hysteresis) with direct Hall sensor measurement.

**Equations:**
- Phi_i = d_Hi * v_Hi (Eq. 4.1) -- flux proportional to Hall voltage
- Phi = D_H * V_H (Eq. 4.2) -- D_H = diag(d_H1,...,d_H6) is Flux-Gain Matrix
- Force model: F(p, b, V_H) = f_Phi * V_H^T * D_H^T * L(p,b) * D_H * V_H (Eq. 4.3)
- Normalized: F = f_hat_H * V_H^T * D_hat_H^T * L(p,b) * D_hat_H * V_H (Eq. 4.4)
  - D_hat_H = D_H / d_H1 = diag(1, d_hat_H2,..., d_hat_H6)
  - f_hat_H is lumped force gain

#### 4.2.2 Current-Based Model with Coupling Structure (pp. 68-69)

- K_I structure (Eq. 4.5): diagonal k1-k6, coupling terms: m (neighboring), s (separated-by-one), epsilon (opposite)
- k1-k6 > m > s > epsilon

#### 4.3 Hall Sensor Hardware (pp. 70-73)

- Hall sensors: **Asahi Kasei EQ-730L**
  - Bandwidth: 100 kHz
  - Sensitivity: 130 mV/mT (typical)
  - Package: 4.1 mm x 3.0 mm x 1.15 mm
  - Hall element: 0.3 mm diameter plate, 0.41 mm from surface
- Cannot place at tip (workspace radius 500 um < sensor size)
- **Surface-mounted** on each pole instead
- **Validated:** Vsurface proportional to Vtip for both self-actuation and coupled actuation (1-3 kHz)
- Time delay between surface and tip measurements is negligible (us scale vs. ms system bandwidth)

#### 4.4 Force Model Calibration (pp. 73-82)

**Hysteresis observed:**
- Current vs. Hall voltage plots show remanent magnetization (bias) in most poles
- Reversing current sign produces different hysteresis loops -- very complicated to model

**Calibration procedure:**
- Steer bead in water along circular trajectories (50 um diameter) in xy, yz, xz planes at 10 um/s
- Two experiments: normal currents and reversed-sign currents (explores different hysteresis loops)
- Low-pass filter applied to remove thermal force and measurement noise effects
- LPF time constant tau = 0.05

**Results:**
- Hall-sensor model: J_H = 2434.42, error per point = 0.087 pN
- Current-based model: J_I = 10279.1, error per point = 0.179 pN
- Hall-sensor model error follows Gaussian distribution (captures physics correctly)

#### 4.5 Applications (pp. 82-90)

**Force prediction (4.5.1):**
- Calibrated Hall-sensor model accurately predicts forces along different trajectories (25 um circles, straight lines)
- Current-based model has obvious errors

**Hall-sensor inner loop control (4.5.2):**
- Secondary control loop directly controls Hall sensor voltage V_m to match desired V_d
- Rise time: ~0.32 ms
- Removes remanent magnetization problem
- AD converter at 200 kHz, Hall feedback at 100 kHz, DA at 640 kHz
- Stabilization error much smaller than current-based control

#### 4.6 Accurate Model with Langevin Function (pp. 90-109)

**Bead magnetization (Eq. 4.12):**
- m(ms, a, B) = ms * [coth(a*|B|) - 1/(a*|B|)] * B_hat
- ms: saturation limit of bead
- a: shape parameter of Langevin function
- Linear approximation (Eq. 4.13): m approx ms * (a/3) * B when |B| -> 0
- Nominal values: ms = 1.50e-12 Am^2, a = 227.8125

**Accurate force model (Eq. 4.17):**
- F_i = f_hat * f_hat_L(a*|B|) * V_H^T * D_hat_H^T * L_i(p,b) * D_hat_H * V_H
- f_hat_L = Langevin Force Gain
- f_hat = ms * k_m^2 * d_H1^2 * a / (4 * rho^5 * mu_0^2)

**Calibration results (Eq. 4.18):**
- Glycerol experiments (larger forces), bead steered at 2 um/s (xy) and 1.5 um/s (yz, xz)
- With Langevin: J_H = 4.3063e5, error per point = 1.58 pN
- Without Langevin: J_H = 1.3859e6, error per point = 2.83 pN
- Calibrated parameters: f_hat = 24.939 pN, a_hat = 3.232
- External field reaches ~260 Gauss in experiment; linear range only up to ~50 Gauss
- Recalculated: ms = 1.40e-12, a = 244.234, b_H = 1.323e-2, d_Hi = 5.99e-8

**Optimal inverse model with Langevin (Eq. 4.19-4.20):**
- Same Lagrange multiplier approach for unit force direction
- f_hat_L(a|B|) * |V|^2 is monotonically increasing -- can be inverted to find |V|
- At small |V|: approximately quadratic; at large |V|: approximately linear (saturated bead)

#### 4.7 Conclusion (pp. 109-110)

Hall sensors solve complicated hysteresis. Sub-pN accuracy demonstrated. Inner loop control removes remanent magnetization. Langevin function needed for large fields (>50 Gauss).

### Chapter 5: Dynamic Force Sensing and Parameter Estimation (pp. 111-130, lines 5208-5957)

#### 5.1 Introduction (pp. 111-112)

Dynamic force sensing transforms the actuator from force applier to active scanning probe. Requires accurate force model + estimation algorithm. Joint state-parameter estimator simultaneously estimates bead-sample interaction force and drag coefficient.

#### 5.2 Estimator Algorithm (pp. 113-119)

**Bead dynamics (Eq. 5.1):** gamma * x_dot(t) = F_MT(t) + F_E(t) + F_T(t)

**State-space model (Eq. 5.7):**
- State: X[k] = [x_E[k], x_E[k-1], (1/gamma)[k]]^T
- 2nd order AR model for disturbance x_E (Eq. 5.5)
- 1st order AR model for 1/gamma (Eq. 5.6)
- Observation: O_m[k] = x_m[k] - x_m[k-1] (position increment)

**Kalman filter (Eqs. 5.9-5.10):**
- Time update: predict state and covariance
- Measurement update: compute innovation, Kalman gain, correct state
- Persistent excitation naturally satisfied (thermal force constantly perturbs bead)

**Two methods for drag estimation:**
1. Based on magnetic force model (Eq. 5.8): 1/gamma as state variable
2. Based on thermal variance (Eq. 5.11-5.12): gamma = 2*k_B*T*tau_s / sigma_T^2

#### 5.3 Simulation Results (pp. 120-125)

- **Water:** Both methods converge to nominal drag coefficient
- **Glycerol:** Magnetic force model method converges; thermal variance method fails (measurement noise comparable to thermal motion)
- **Simultaneous estimation:** Drag coefficient and external force can both converge even when changing simultaneously
- Force estimation bandwidth: ~4.42 Hz; drag estimation bandwidth: ~1 Hz

#### 5.4 Experimental Results (pp. 125-129)

- Hall-sensor model: gamma[k] closely matches PSD-calibrated nominal value; F_E < 0.2 pN (sub-pN dynamic force sensing)
- Current-based model: large discrepancy in drag coefficient, especially in y and z directions; inconsistent across experiments due to hysteresis history

#### 5.5 Conclusion (pp. 129-130)

Joint state-parameter estimator validated. Hall-sensor model greatly outperforms current-based model for force sensing. Sub-pN force sensing demonstrated.

### Chapter 6: Conclusion and Future Works (pp. 131-135, lines 5958-6167)

**Summary of achievements:**
1. Hardware design with 1018 steel, >2T saturation, 40 um tip radius
2. Lumped-parameter force model (quadratic in current/flux)
3. Optimal inverse model (minimal 2-norm currents, <5% error in workspace)
4. FPGA control at 1606 Hz, Brownian std dev ~30 nm
5. Hall-sensor model: sub-pN accuracy, bypasses hysteresis
6. Langevin function for nonlinear bead magnetization
7. Kalman filter joint state-parameter estimator

**Future work:**
1. Implement estimator in FPGA for real-time force monitoring
2. Biological experiments (intracellular scanning, cytoplasm property sensing)
3. Optimal inverse model based on calibrated force model (for high-bandwidth tracking)

### Bibliography (pp. 136-141, lines 6168-6432)

83 references. Key references for our work:
- [1] Zhang, Long and Menq 2013 -- 3D visual servo control
- [2] Zhang and Menq 2011 -- Design and modeling of 3D actuator (previous thin-foil design)
- [52] Zhang, Huang and Menq 2010 -- Quadrupole magnetic tweezers (force model origin)
- [53] Zhang, Huang and Menq 2010 -- Design and force modeling of quadrupole
- [63] Chen et al. 2015 -- Competing MT design (FEM look-up table, no analytical model)
- [67] Chikazumi 1964 -- Physics of magnetism (gradient force formula)
- [77] Fonnum et al. 2005 -- Dynabead characterization (ms = 1.50e-12)

## Equations and Parameters We Use

### Device Parameters

| Parameter | Value | Context | Page |
|---|---|---|---|
| Pole material | 1018 steel (0.18% C) | Low-carbon steel, high saturation | p.14 |
| Saturation limit | >2T | Material property | p.14 |
| Pole diameter | ~6 mm | Pole cross-section | p.14 |
| Upper pole length | ~45 mm | Physical dimension | p.14 |
| Lower pole length | ~42 mm | Milled flat for dish | p.14 |
| Pole tip radius | 40 um | Included in FEM | p.14 |
| Workspace radius (physical) | 500 um | Tip-to-center distance | p.14 |
| Workspace radius (charge model) | 900 um | Best-fit parameter from FEM | p.20 |
| Air reluctance | 6.3e8 A/Wb | Best-fit parameter from FEM | p.20 |
| Coil turns | 70 | Per coil | p.14 |
| Max current | 3 A | Linear range verified | p.39 |
| Bead diameter | 4.5 um | Dynabead M-450 Epoxy | p.14 |
| Bead saturation | 1.50e-12 Am^2 (nominal) | Magnetic moment | p.93 |
| Bead saturation (recalculated) | 1.40e-12 Am^2 | From calibration | p.105 |
| Langevin shape parameter a | 227.8 (nominal), 244.2 (recal.) | Magnetization curve | p.93, 105 |
| Linear magnetization range | up to ~50 Gauss | Beyond this, Langevin needed | p.91, 105 |
| k_m = mu_0/(4*pi) | 1.0e-7 N/A^2 | Permeability constant | p.18 |
| Cover glass thickness | ~100 um | Between upper/lower planes | p.13 |
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

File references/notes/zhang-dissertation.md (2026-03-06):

# Magnetic Tweezers: Actuation, Measurement, and Control at Nanometer Scale

## Bibliographic Info

| Field | Value |
|---|---|
| Authors | Zhipeng Zhang |
| Year | 2009 |
| Type | PhD Dissertation |
| Source | The Ohio State University, Department of Mechanical Engineering |
| Advisor | Professor Chia-Hsiang Menq |
| Committee | K. Srinivasan, M. Dapino, J. Wang |
| PDF file | pdfs/Zhipeng Zhang.pdf |
| Total pages | 165 (xxii + 143 numbered pages) |

## Relevance to This Project
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

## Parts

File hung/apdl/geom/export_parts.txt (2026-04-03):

! Export all simulation parts as individual IGES (SolidWorks units)
! Output to hung/IGES/
/CWD,'C:\Users\pmero\Documents\Lab406\magnetic-tweezers-sim\hung\IGES'

! ============================================================
! Part 1: Mag_Pole_Bottom (D-shape pole along +X axis)
! ============================================================
/CLEAR, NOSTART
/PREP7
*afun, DEG
MM = 1.0/25.4

POLE_R         = 3.175*MM
POLE_CONE_LEN  = 15.875*MM
POLE_TOTAL_LEN = 43.0*MM
POLE_FLAT_LEN  = 28.0*MM

! Tip at origin, axis = +X, side_perp = +Y
! Front section (D-shape, 0~28mm): VROTAT 180°
K, 1, 0, 0, 0                                          ! tip
K, 2, POLE_CONE_LEN, POLE_R, 0                         ! cone-cyl junction
K, 3, POLE_FLAT_LEN, POLE_R, 0                         ! flat cut boundary
K, 4, POLE_FLAT_LEN, 0, 0                              ! flat cut boundary (axis)
K, 5, POLE_TOTAL_LEN, 0, 0                             ! far end (axis)

L, 1, 2
L, 2, 3
L, 3, 4
L, 4, 1
AL, 1, 2, 3, 4
VROTAT, 1, ,,,, , 1, 5, 180, 2

ALLSEL, ALL

! Back section (full round, 28~43mm): VROTAT 360°
*get, KP_NUM, KP, , NUM, MAX
KS = KP_NUM + 1
NUMSTR, KP, KS
*get, LI_NUM, LINE, , NUM, MAX
LS = LI_NUM + 1
NUMSTR, LINE, LS

K, KS,   POLE_FLAT_LEN, 0, 0
K, KS+1, POLE_FLAT_LEN, POLE_R, 0
K, KS+2, POLE_TOTAL_LEN, POLE_R, 0
K, KS+3, POLE_TOTAL_LEN, 0, 0

L, KS, KS+1
L, KS+1, KS+2
L, KS+2, KS+3
L, KS+3, KS

*get, AR_NUM, AREA, , NUM, MAX
AS = AR_NUM + 1
NUMSTR, AREA, AS
AL, LS, LS+1, LS+2, LS+3
VROTAT, AS, ,,,, , KS, KS+3, , 4

ALLSEL, ALL
IGESOUT, 'Mag_Pole_Bottom', 'iges'
*msg, INFO
 Part 1: Mag_Pole_Bottom exported

! ============================================================
! Part 2: Pole_Block_Top (upper block, L-shape, 25x22x10mm)
! ============================================================
/CLEAR, NOSTART
/PREP7
*afun, DEG
MM = 1.0/25.4
BLK_T = 10.0*MM

! L-shape cross-section in XY plane, extrude along Z
! Part1: X [-0.25, 12.75], Y [-11, 11] mm (main body)
! Part2: X [-12.25, -0.25], Y [-5, 5] mm (extension)
BLOCK, -0.25*MM, 12.75*MM, -11*MM, 11*MM, 0, BLK_T
BLOCK, -12.25*MM, -0.25*MM, -5*MM, 5*MM, 0, BLK_T

*get, V2, VOLU, 0, NUM, MAX
VADD, V2-1, V2

ALLSEL, ALL
IGESOUT, 'Pole_Block_Top', 'iges'
*msg, INFO
 Part 2: Pole_Block_Top exported

! ============================================================
! Part 3: Pole_Block_Bottom (lower block, L-shape, 22x22x10mm)
! ============================================================
/CLEAR, NOSTART
/PREP7
*afun, DEG
MM = 1.0/25.4
BLK_T = 10.0*MM

! Part1: X [2, 9], Y [-11, 11] mm
! Part2: X [-13, 2], Y [-5, 5] mm
BLOCK, 2*MM, 9*MM, -11*MM, 11*MM, 0, BLK_T
BLOCK, -13*MM, 2*MM, -5*MM, 5*MM, 0, BLK_T

*get, V2, VOLU, 0, NUM, MAX
VADD, V2-1, V2

ALLSEL, ALL
IGESOUT, 'Pole_Block_Bottom', 'iges'
*msg, INFO
 Part 3: Pole_Block_Bottom exported

! ============================================================
! Part 4: Mag_Guide_Post (cylinder R=4mm, H=41mm)
! ============================================================
/CLEAR, NOSTART
/PREP7
*afun, DEG
MM = 1.0/25.4

CYL4, 0, 0, 4.0*MM, 0, , 360, 41.0*MM

ALLSEL, ALL
IGESOUT, 'Mag_Guide_Post', 'iges'
*msg, INFO
 Part 4: Mag_Guide_Post exported

! ============================================================
! Part 5: Coil (ring R_in=10, R_out=12, H=15mm)
! ============================================================
/CLEAR, NOSTART
/PREP7
*afun, DEG
MM = 1.0/25.4

CYL4, 0, 0, 10.0*MM, 0, 12.0*MM, 360, 15.0*MM

ALLSEL, ALL
IGESOUT, 'Coil', 'iges'
*msg, INFO
 Part 5: Coil exported

! ============================================================
! Part 6: Mag_Iron_Ring (yoke R_in=38, R_out=62.5, T=2mm)
! ============================================================
/CLEAR, NOSTART
/PREP7
*afun, DEG
MM = 1.0/25.4

CYL4, 0, 0, 38.0*MM, 0, 62.5*MM, 360, 2.0*MM

ALLSEL, ALL
IGESOUT, 'Mag_Iron_Ring', 'iges'
*msg, INFO
 Part 6: Mag_Iron_Ring exported

FINISH

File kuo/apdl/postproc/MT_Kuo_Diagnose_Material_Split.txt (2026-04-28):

! ====================================================================
! [ADDED] Diagnose energy split by material:
!   - Iron (MAT=1, μ_r=8000): use W = ∫B²/(2 × μ_r × μ_0) dV
!   - Air  (MAT=2, μ_r=1):    use W = ∫B²/(2 × μ_0) dV
! Test hypothesis: prior manual calc overestimated by treating iron with μ_0
! ====================================================================

! /CWD removed; use ANSYS -dir command-line arg instead
/CLEAR, NOSTART
/FILNAME, kuo_singlecoil_sim
RESUME, 'sim_solved', 'db'
/POST1
SET, LAST

MM      = 1.0e-3
MU0     = 4*3.141592653589793*1e-7
MU_R_FE = 8000

! Build B² × V per element table
ETABLE, BX_E, B, X
ETABLE, BY_E, B, Y
ETABLE, BZ_E, B, Z
ETABLE, EVOL, VOLU
SMULT, B2X, BX_E, BX_E, 1, 1
SMULT, B2Y, BY_E, BY_E, 1, 1
SMULT, B2Z, BZ_E, BZ_E, 1, 1
SADD,  B2_XY, B2X, B2Y, 1, 1
SADD,  B2_TOT, B2_XY, B2Z, 1, 1
SMULT, B2V, B2_TOT, EVOL, 1, 1

! ===== Iron: MAT 1 =====
ESEL, S, MAT, , 1
*GET, NE_FE, ELEM, , COUNT
SSUM, , B2V
*GET, INT_FE, SSUM, 0, ITEM, B2V
W_FE_PROPER = INT_FE/(2*MU_R_FE*MU0)
W_FE_NAIVE  = INT_FE/(2*MU0)
*MSG, INFO, NE_FE, INT_FE
 IRON_ELEMS= %I  IRON_INT_B2V= %G
*MSG, INFO, W_FE_PROPER
 IRON_W_PROPER_DIVIDED_BY_MU_R = %G JOULES
*MSG, INFO, W_FE_NAIVE
 IRON_W_NAIVE_DIVIDED_BY_MU0   = %G JOULES

! ===== Air: MAT 2 =====
ESEL, S, MAT, , 2
*GET, NE_AIR, ELEM, , COUNT
SSUM, , B2V
*GET, INT_AIR, SSUM, 0, ITEM, B2V
W_AIR = INT_AIR/(2*MU0)
*MSG, INFO, NE_AIR, INT_AIR
 AIR_ELEMS= %I  AIR_INT_B2V= %G
*MSG, INFO, W_AIR
 AIR_W = %G JOULES

! ===== Totals =====
W_TOT_PROPER = W_FE_PROPER + W_AIR
L_PROPER     = 2*W_TOT_PROPER

W_TOT_NAIVE = W_FE_NAIVE + W_AIR
L_NAIVE     = 2*W_TOT_NAIVE

*MSG, INFO, W_TOT_PROPER, L_PROPER
 W_PROPER= %G JOULES, L_PROPER= %G HENRY
*MSG, INFO, W_TOT_NAIVE, L_NAIVE
 W_NAIVE= %G JOULES, L_NAIVE= %G HENRY

! ===== Also check max |B| in iron =====
ETABLE, BSUM_E, B, SUM      ! magnitude of B vector
ESEL, S, MAT, , 1
ESORT, ETAB, BSUM_E, 0      ! sort descending
*GET, B_MAX_FE, SORT, 0, MAX
*MSG, INFO, B_MAX_FE
 MAX_BMAG_IN_IRON = %G TESLA

ALLSEL, ALL
FINISH
/EXIT, NOSAV

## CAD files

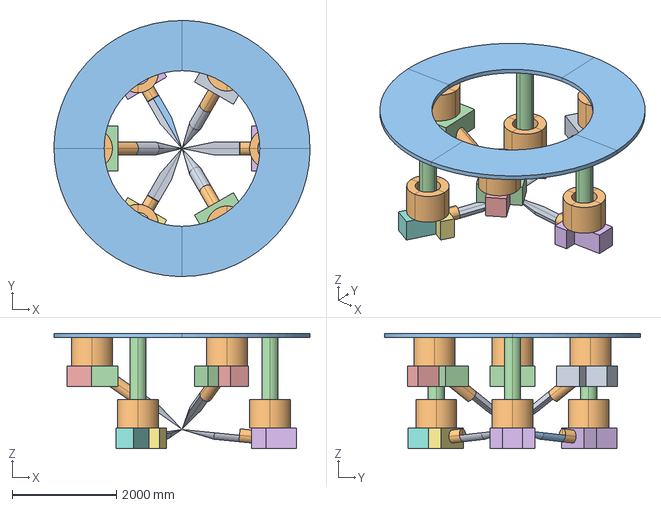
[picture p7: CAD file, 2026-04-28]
hung/IGES/Full_Assembly_Dfillet_l250.iges
4921.3 x 4921.3 x 2213.2 mm

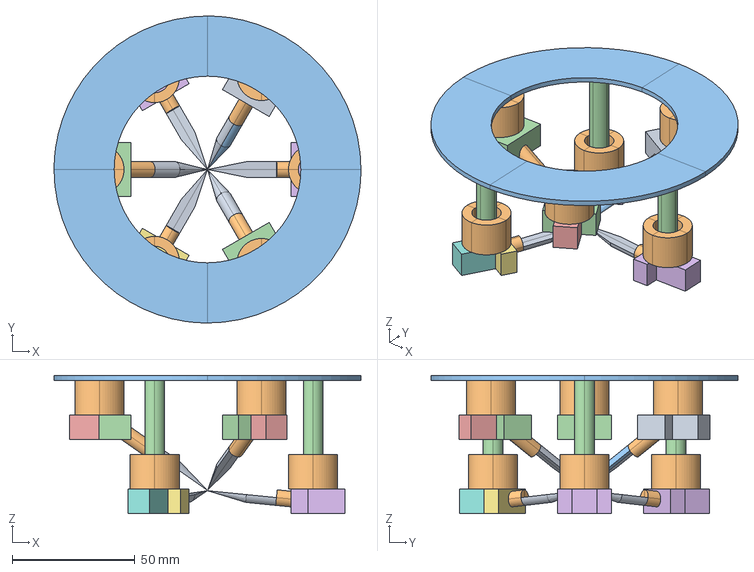
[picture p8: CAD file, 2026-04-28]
hung/IGES_converted/Full_Assembly_Dfillet_l250.iges
125.0 x 125.0 x 56.2 mm

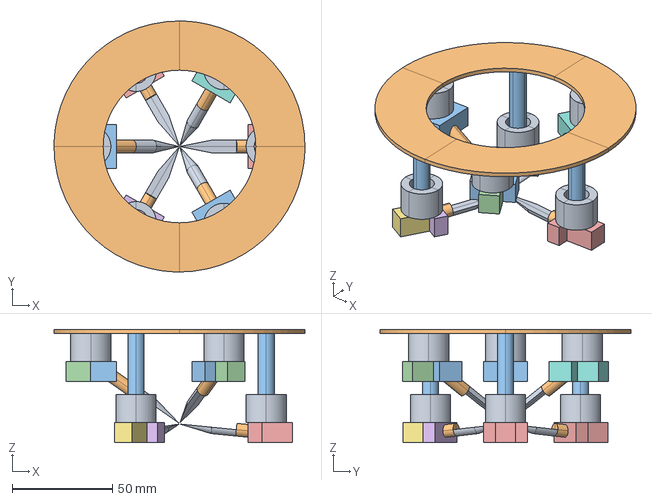
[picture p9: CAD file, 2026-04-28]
hung/IGES_converted/Full_Assembly_filleted.iges
125.0 x 125.0 x 56.5 mm

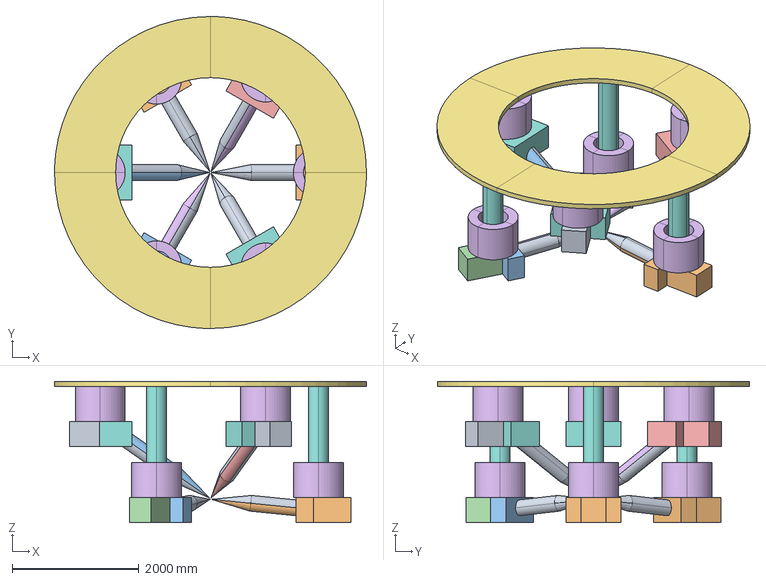
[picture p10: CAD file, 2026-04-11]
hung/IGES/Full_Assembly_round_filleted.iges
4921.3 x 4921.3 x 2224.6 mm

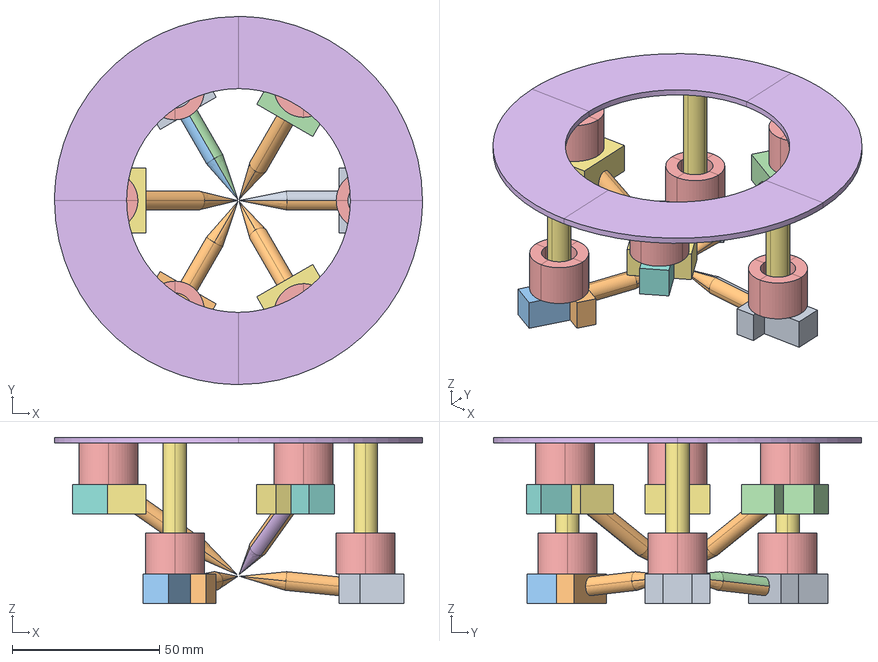
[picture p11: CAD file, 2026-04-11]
hung/IGES_converted/Full_Assembly_round_filleted.iges
125.0 x 125.0 x 56.5 mm

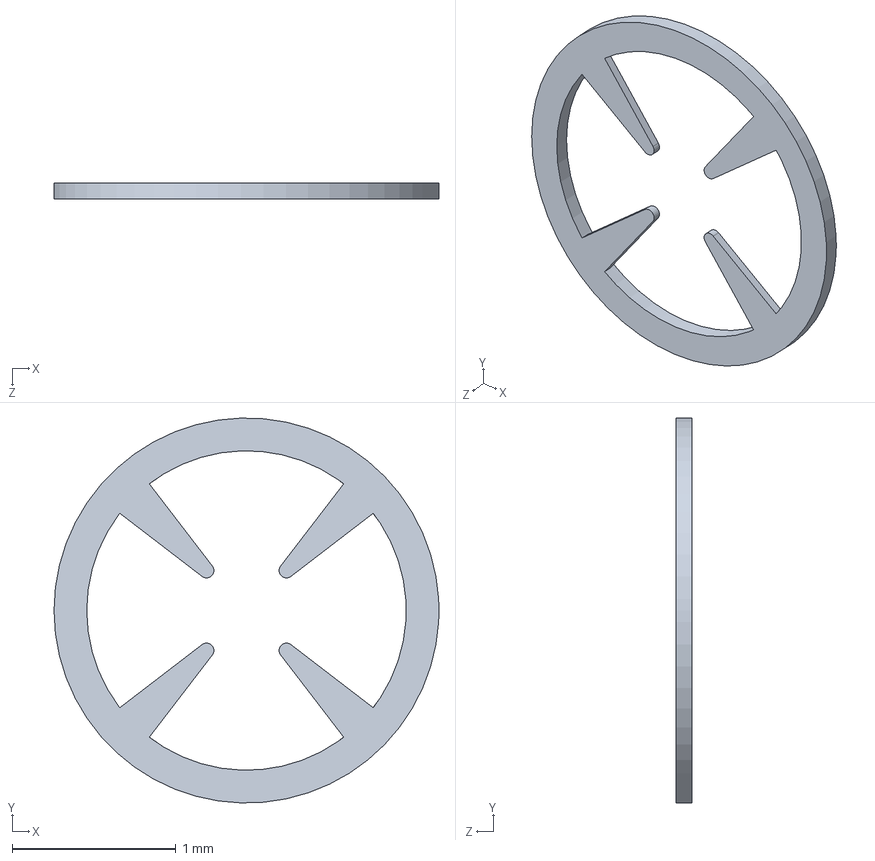
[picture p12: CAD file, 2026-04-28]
kuo/CAD/SLDPRT/0.67mm_baseline.SLDPRT
2.35 x 2.35 x 0.1 mm

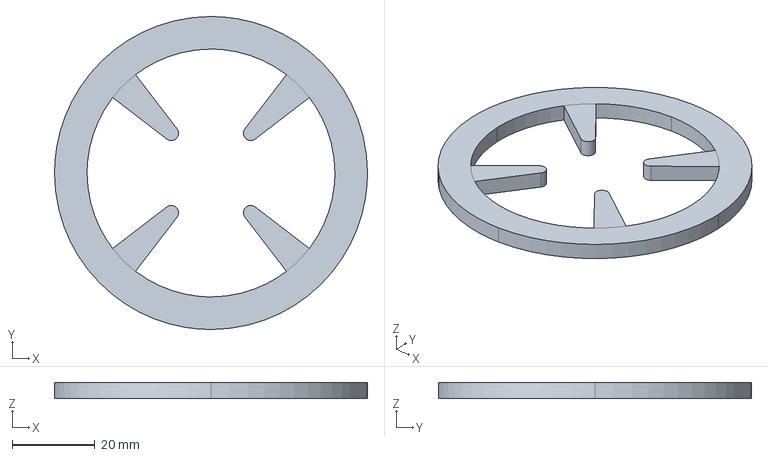
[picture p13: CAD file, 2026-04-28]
kuo/IGES/Quadrupole_Lp046_T100.iges
75.6 x 75.6 x 3.94 mm

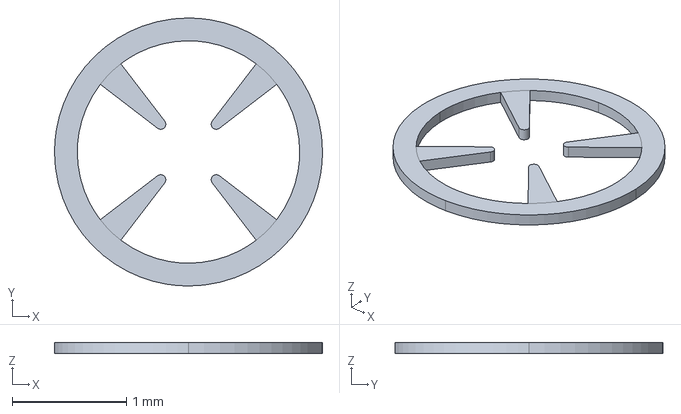
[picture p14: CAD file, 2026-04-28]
kuo/IGES_converted/Quadrupole_Lp067_T100.iges
2.35 x 2.35 x 0.1 mm

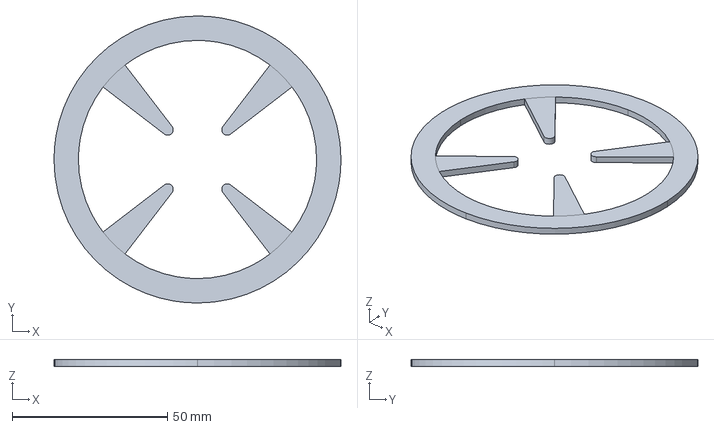
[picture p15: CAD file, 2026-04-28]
kuo/IGES/Quadrupole_Lp067.iges
92.5 x 92.5 x 2.17 mm

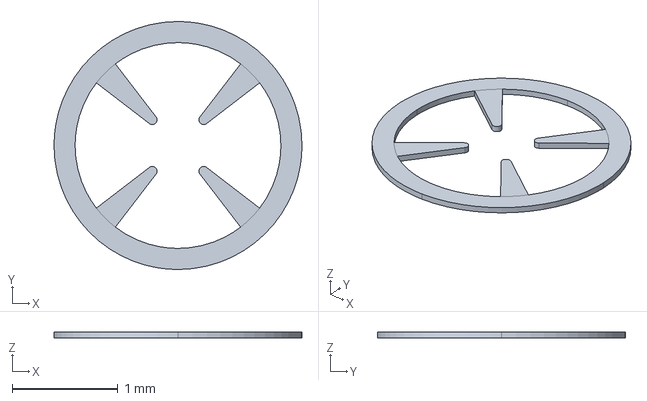
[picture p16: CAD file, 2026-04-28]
kuo/IGES_converted/Quadrupole_Lp067.iges
2.35 x 2.35 x 0.055 mm

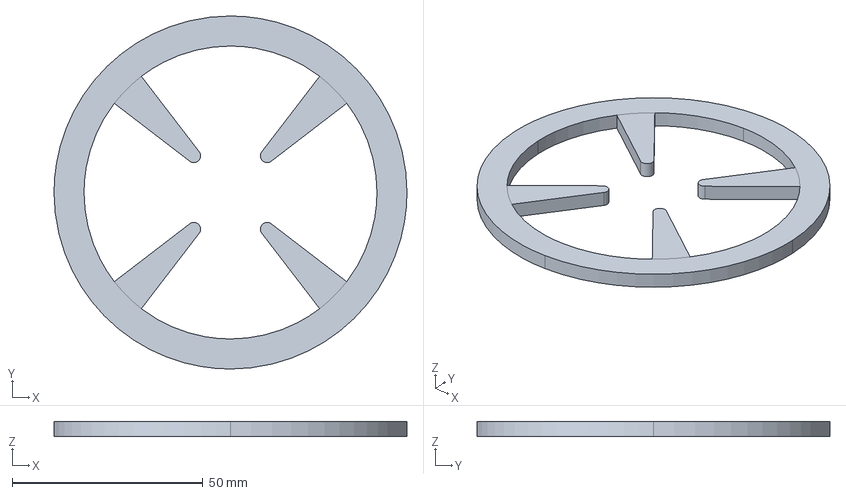
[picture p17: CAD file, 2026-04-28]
kuo/IGES/Quadrupole_Lp067_T100.iges
92.5 x 92.5 x 3.94 mm

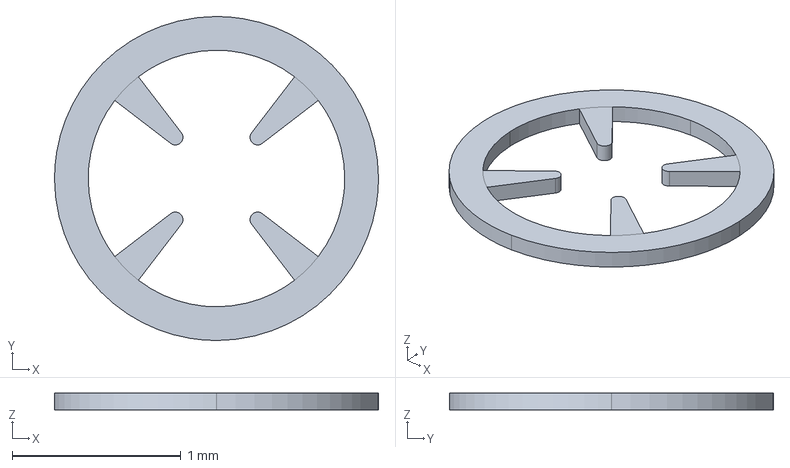
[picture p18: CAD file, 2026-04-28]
kuo/IGES_converted/Quadrupole_Lp046_T100.iges
1.92 x 1.92 x 0.1 mm

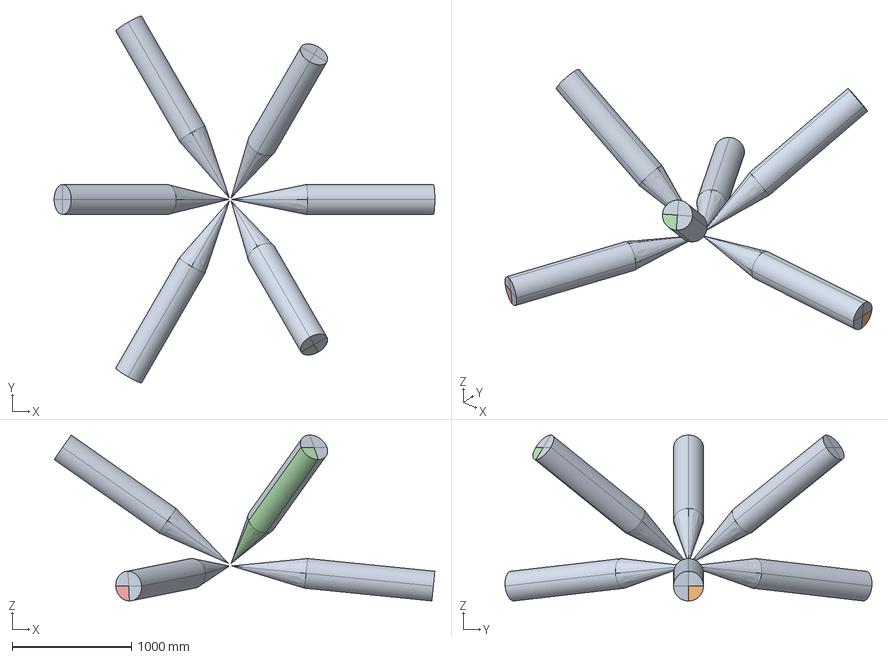
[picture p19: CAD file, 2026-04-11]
hung/IGES/Poles_round_filleted.iges
3187.5 x 3072.3 x 1389.0 mm

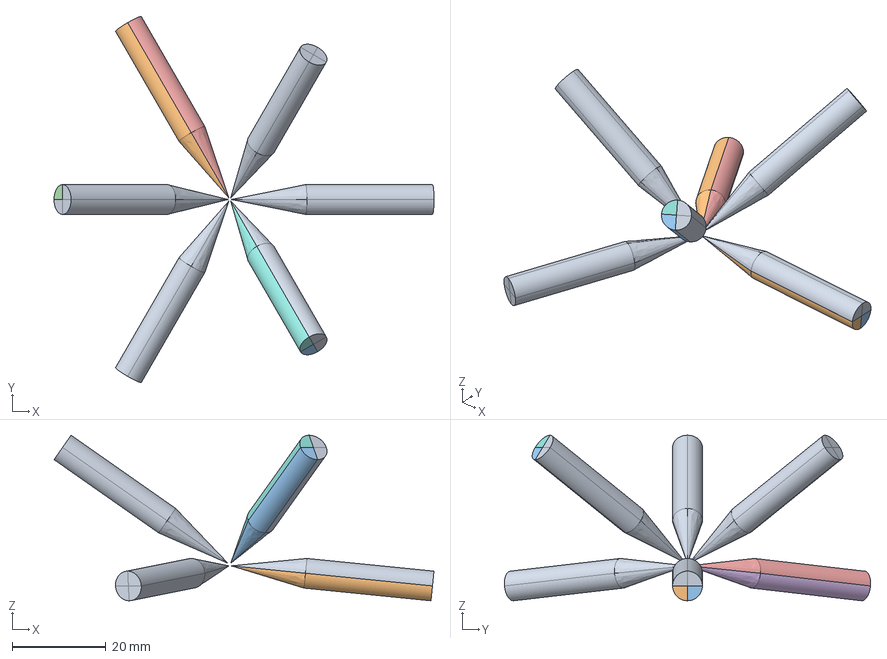
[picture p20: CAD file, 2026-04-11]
hung/IGES_converted/Poles_round_filleted.iges
81.0 x 78.0 x 35.3 mm

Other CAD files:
hung/IGES/Full_Assembly_filleted.iges
hung/IGES_converted/Full_Assembly.iges
kuo/CAD/STEP/0.67mm.STEP
hung/IGES/Mag_Pole_Bottom_filleted.iges
hung/IGES/Coil.iges
hung/IGES/Mag_Guide_Post.iges
hung/IGES/Mag_Pole_Bottom.iges
hung/IGES/Pole_Block_Bottom.iges
hung/IGES/Pole_Block_Top.iges
hung/IGES/Upper_Ring.iges
hung/IGES_converted/Coil.iges
hung/IGES_converted/Mag_Guide_Post.iges
hung/IGES_converted/Mag_Pole_Bottom.iges
hung/IGES_converted/Mag_Pole_Bottom_filleted.iges
hung/IGES_converted/Pole_Block_Bottom.iges
hung/IGES_converted/Pole_Block_Top.iges
hung/IGES_converted/Upper_Ring.iges

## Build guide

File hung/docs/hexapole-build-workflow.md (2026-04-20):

# Hexapole Pole Tip 建模流程

## 步驟 1：決定 tip 位置

### 請使用者提供以下資訊

> **問題 1：球體半徑 R 是多少 mm？**
>
> 這是每個 pole tip 到 working point（球心）的距離。
> 同一 pair 的 tip-to-tip 距離 = 2×R。
>
> 例如：R = 0.5 mm → tip-to-tip = 1.0 mm

> **問題 2：相鄰 pole 的間距角度是多少度？**
>
> 從俯視圖看，相鄰兩根 pole 之間的方位角間距。
> 標準 hexapole = 60°（6 根 pole 均勻分布 360°）。
>
> 例如：spacing = 60°

### 輸入參數總表

| # | 參數 | 說明 | 範例 |
|---|---|---|---|
| 1 | 球體半徑 R (mm) | 每個 tip 到 working point 的距離 | 0.5 |
| 2 | Pole 間距角度 (°) | 相鄰 pole 在俯視圖的方位角間距 | 60 |

### Pole 編號與排列（俯視圖，逆時針）

X+ 方向固定指向 P1。

```
              P5 (upper, 60°)
             /
P3 (lower, 120°)       P1 (lower, 0°) → X+
             \         /
              ● center
             /         \
P2 (upper, 180°)       P4 (upper, 300°)
             \
              P6 (lower, 240°)
```

| 方位角 | Pole | 層 | Pair |
|---|---|----|---|
| 0° | P1 | lower | I |
| 60° | P5 | upper | III |
| 120° | P3 | lower | II |
| 180° | P2 | upper | I |
| 240° | P6 | lower | III |
| 300° | P4 | upper | II |

對面 pole 相差 180°，同一 pair：P1↔P2、P3↔P4、P6↔P5。
上下層交替排列，每隔 60°。

### 座標系對齊

**ANSYS 座標系 = Measured 座標系**，不需要額外轉換：

| 軸 | ANSYS 方向 | Measured 方向 | 指向 |
|----|---|---|---|
| +X | +X | X_m | P1 (0°) |
| +Y | +Y | Y_m 投影 | P5 方向 (60°) |
| +Z | +Z | 垂直向上 | 上層 tip 側 |

SolidWorks 開 IGES 後看到的方向直接對應 measured 座標系：
- **+X 方向的 pole = P1**
- **右上 60° 方向 = P5**
- **左邊 180° = P2**

### 執行方式

使用者回答問題後，Claude 自動將值代入 MATLAB 程式碼中的 `[USER]` 變數並執行。

### 輸出

2 張 MATLAB 圖：

1. **3D 球面圖**（`step1_sphere_3D.png`）：6 個 tip 點在球面上的位置，標注 P1-P6 編號與 upper/lower
2. **俯視圖**（`step1_topview.png`）：X+ 指向 P1，標注編號、間距角度、upper/lower

### MATLAB 程式碼

```matlab
%% ===== Step 1: Pole Tip Positions =====
% ===== [USER] 使用者修改這兩行 =====
R = 0.5;          % [USER] 球體半徑 (mm)
spacing = 60;     % [USER] pole 間距角度 (°)

% Magic angle: cos^2(theta) = 1/3
theta_deg = acosd(1/sqrt(3));  % 54.74° (極角)
h = R*cosd(theta_deg);         % 上層平面高度
r = R*sind(theta_deg);         % 上層圓半徑

% Pole 定義 (X+ 指向 P1, 逆時針排列)
pole_names = {'P1','P5','P3','P2','P6','P4'};
pole_types = {'lower','upper','lower','upper','lower','upper'};
pole_az = [0, 60, 120, 180, 240, 300];

% Tip 座標
tips = zeros(6,3);
for i = 1:6
    phi = pole_az(i);
    if strcmp(pole_types{i},'upper')
        tips(i,:) = [r*cosd(phi), r*sind(phi), h];
    else
        tips(i,:) = [r*cosd(phi), r*sind(phi), -h];
    end
end
pair_idx = [1 4; 3 6; 5 2]; % P1↔P2, P3↔P4, P6↔P5

up_clr = [0 0.4 0.8]; lo_clr = [0.8 0.2 0.2];

%% 圖 1：3D 球面圖
fig1 = figure('Color','w','Position',[50 50 800 700]);
[xs,ys,zs] = sphere(40);
surf(xs*R, ys*R, zs*R, 'FaceAlpha',0.1, 'EdgeAlpha',0.06, 'FaceColor',[0.7 0.8 1]);
hold on; axis equal; grid on;
tt = linspace(0, 2*pi, 200);
plot3(r*cos(tt), r*sin(tt), h*ones(size(tt)), 'b--', 'LineWidth',1);
plot3(r*cos(tt), r*sin(tt), -h*ones(size(tt)), 'r--', 'LineWidth',1);
for i = 1:6
    if strcmp(pole_types{i},'upper')
        clr = up_clr; mk = 'v';
    else
        clr = lo_clr; mk = '^';
    end
    plot3(tips(i,1), tips(i,2), tips(i,3), mk, ...
        'MarkerSize',12, 'MarkerFaceColor',clr, 'Color',clr);
    text(tips(i,1)*1.5, tips(i,2)*1.5, tips(i,3)*1.2, ...
        sprintf('%s (%s)', pole_names{i}, pole_types{i}), ...
        'FontSize',11, 'FontWeight','bold', 'Color',clr, ...
        'HorizontalAlignment','center');
end
for k = 1:3
    i1 = pair_idx(k,1); i2 = pair_idx(k,2);
    plot3([tips(i1,1) tips(i2,1)], [tips(i1,2) tips(i2,2)], ...
        [tips(i1,3) tips(i2,3)], 'k--', 'LineWidth',1.2);
end
plot3(0,0,0, 'k+', 'MarkerSize',15, 'LineWidth',2.5);
xlabel('X (mm)'); ylabel('Y (mm)'); zlabel('Z (mm)');
title(sprintf('Step 1: Pole Tip Positions (R = %.1f mm)', R));
view(35, 25);
print(fig1, 'step1_sphere_3D.png', '-dpng', '-r200');

%% 圖 2：俯視圖 (Top View) — Measured 座標系
fig2 = figure('Color','w','Position',[50 50 1000 1000]);
hold on; axis equal; axis off;
tt = linspace(0, 2*pi, 200);
line_len = R*2.0;
for i = 1:6
    phi = pole_az(i);
    if strcmp(pole_types{i},'upper')
        clr = up_clr;
    else
        clr = lo_clr;
    end
    plot([0, line_len*cosd(phi)], [0, line_len*sind(phi)], '-', ...
        'Color', clr, 'LineWidth', 4);
    plot(tips(i,1), tips(i,2), 'o', 'MarkerSize', 10, ...
        'MarkerFaceColor', clr, 'Color', 'k', 'LineWidth', 1.5);
    text(R*2.7*cosd(phi), R*2.7*sind(phi), ...
        sprintf('%s\n(%s)', pole_names{i}, pole_types{i}), ...
        'FontSize', 14, 'FontWeight', 'bold', 'Color', clr, ...
        'HorizontalAlignment', 'center', 'VerticalAlignment', 'middle');
end
% Pair 虛線
for k = 1:3
    i1 = pair_idx(k,1); i2 = pair_idx(k,2);
    p1 = line_len*[cosd(pole_az(i1)), sind(pole_az(i1))];
    p2 = line_len*[cosd(pole_az(i2)), sind(pole_az(i2))];
    plot([p1(1) p2(1)], [p1(2) p2(2)], 'k--', 'LineWidth', 1);
end
% 間距弧線
arc_r = R*1.5;
for i = 1:6
    a1 = pole_az(i);
    if i < 6
        a2 = pole_az(i+1);
    else
        a2 = pole_az(1) + 360;
    end
    arc_a = linspace(a1, a2, 30);
    plot(arc_r*cosd(arc_a), arc_r*sind(arc_a), '-', 'Color', [0.5 0.5 0.5]);
    mid_a = (a1 + a2)/2;
    text(arc_r*1.12*cosd(mid_a), arc_r*1.12*sind(mid_a), ...
        sprintf('%d°', spacing), 'FontSize', 11, 'Color', [0.4 0.4 0.4], ...
        'HorizontalAlignment', 'center');
end
% Measured 座標系：X_m → P1 (0°), Y_m → P5 (60°)
ax_len = R*0.85;
red = [0.85 0 0];
plot([0 ax_len], [0 0], '-', 'Color', red, 'LineWidth', 2.5);
plot(ax_len, 0, '>', 'Color', red, 'MarkerFaceColor', red, 'MarkerSize', 8);
text(ax_len+0.05, -0.02, 'X_m', 'FontSize', 13, 'FontWeight', 'bold', 'Color', red);
plot([0 ax_len*cosd(60)], [0 ax_len*sind(60)], '-', 'Color', red, 'LineWidth', 2.5);
plot(ax_len*cosd(60), ax_len*sind(60), '^', 'Color', red, 'MarkerFaceColor', red, 'MarkerSize', 8);
text(ax_len*cosd(60)+0.04, ax_len*sind(60)+0.02, 'Y_m', ...
    'FontSize', 13, 'FontWeight', 'bold', 'Color', red);
plot(0, 0, 'k.', 'MarkerSize', 10);
% 圖例
lx0 = -R*2.8; ly0 = -R*2.5;
plot(lx0, ly0, 'o', 'MarkerSize', 8, 'MarkerFaceColor', up_clr, 'Color', 'k');
text(lx0+0.05, ly0, 'upper pole', 'FontSize', 12, 'Color', up_clr, ...
    'FontWeight', 'bold', 'VerticalAlignment', 'middle');
plot(lx0, ly0-0.12, 'o', 'MarkerSize', 8, 'MarkerFaceColor', lo_clr, 'Color', 'k');
text(lx0+0.05, ly0-0.12, 'lower pole', 'FontSize', 12, 'Color', lo_clr, ...
    'FontWeight', 'bold', 'VerticalAlignment', 'middle');
plot([lx0 lx0+0.06], [ly0-0.24 ly0-0.24], 'k--', 'LineWidth', 1);
text(lx0+0.08, ly0-0.24, 'pair connecting line', 'FontSize', 10, ...
    'Color', [0.3 0.3 0.3], 'VerticalAlignment', 'middle');
title(sprintf('Top View (Measured coord.): R = %.1f mm, spacing = %d°', R, spacing), 'FontSize', 14);
margin = R*3.2;
xlim([-margin margin]); ylim([-margin margin]);
print(fig2, 'step1_topview.png', '-dpng', '-r200');
```

---

## 步驟 2：擺放 pole 並建立 APDL 模型

### 請使用者提供以下資訊

> **問題：你的上層和下層 pole 要以什麼角度擺放？**
>
> 請參考下圖，回答兩個角度：

```
        Block (上, 外)
            \
             \  α_upper（上層傾斜角）
              \_________ 水平面
               \
                Tip (下, 內)          ← upper pole (P2, P4, P5)
                                       從 tip 沿軸往上、往外延伸到 block

                Tip (上, 內)          ← lower pole (P1, P3, P6)
               /  α_lower（下層傾斜角）
              /_________ 水平面
             /
        Block (下, 外)                 從 tip 沿軸往下、往外延伸到 block
```

| # | 參數 | 說明 | 範例 |
|---|---|---|---|
| 3 | α_upper (°) | 上層 pole 相對水平往上的傾斜角 | 35° |
| 4 | α_lower (°) | 下層 pole 相對水平往下的傾斜角 | 5.71° |

> **注意**：兩個角度都填正值。上層代表「往上幾度」，下層代表「往下幾度」。

### 執行方式

使用者回答問題後，Claude 自動將值代入 APDL 程式碼中的 `[USER]` 變數、執行 ANSYS、匯出 IGES。

### Pole 尺寸（from Mag_Pole_Bottom.STEP）

| 參數 | 值 | 說明 |
|---|-----|---|
| 圓柱半徑 | 3.175 mm | |
| 錐段長度 | 15.875 mm | semi-angle 11.31° |
| 總長 | 43 mm | |
| Tip | 尖錐頂點 | STEP 無 fillet |

### 輸出

- IGES 檔案 → SolidWorks 開啟量測驗證
- 使用者在 SolidWorks 量 tip-to-tip 距離，應為 2×R（例如 1.0 mm）

### APDL 注意事項

| # | 陷阱 | 解法 |
|---|---|---|
| 1 | 乘號 `*` 前後有空格 → APDL 當成註解 | `cos(theta)*R_sphere`（不留空格） |
| 2 | IGES 單位：ANSYS 寫 meters，SolidWorks 讀成 inches | 內部用 `MM = 1.0/25.4` 轉英寸 |
| 3 | Magic angle 搞混極角/仰角 | 極角 θ = acosd(1/√3) = 54.74° |
| 4 | VROTAT 接縫與削平面重合 | 截面偏移用 profile45 旋轉 45° |

### APDL 程式碼（已測試通過）

使用者需修改的參數標記為 `[USER]`。
含座標對齊（ANSYS +X = P1）、兩段式削平（前段 D 型 + 後段全圓）。

- **上層 pole**：削平面朝上
- **下層 pole**：削平面朝下（轉 180°）

完整腳本見 `hung/apdl/variants/MT_Hung_SphereModel.txt`，以該檔案為準。

### 削平方法

不使用 VSBV（已知會失敗），改用**兩段式 VROTAT**：

| 段 | 範圍 | VROTAT | 結果 |
|----|---|---|---|
| 前段 | tip → 28mm | 180°, 2 divisions | D 型半圓（削平） |
| 後段 | 28mm → 43mm | 360°, 4 divisions | 全圓柱 |

削平面方向由截面偏移決定：
- Upper pole: `-side_perp` → 保留下半 → 削平面朝上
- Lower pole: `+side_perp` → 保留上半 → 削平面朝下

### SolidWorks 驗證清單（步驟 2）

- [ ] P1 在 +X 方向（SolidWorks 右邊）
- [ ] tip-to-tip 距離 = 2×R mm
- [ ] 俯視 60° 等距
- [ ] 前段 D 型、後段全圓柱
- [ ] 上層削平面朝上、下層朝下

---

## 步驟 3：安裝 Block

### 請使用者提供以下資訊

> **問題 5：上層 pole 伸入 block 多少 mm？（沿 pole 軸量）**
> 例如：7mm
>
> **問題 6：下層 pole 伸入 block 多少 mm？（沿 pole 軸量）**
> 例如：4.5mm

### 輸入參數

| # | 參數 | 說明 | 範例 |
|---|---|---|---|
| 5 | 上層伸入量 (mm) | pole 尾端沿軸進入 block 的深度 | 7 |
| 6 | 下層伸入量 (mm) | 同上 | 4.5 |

### 執行方式

使用者回答後，Claude 自動代入 APDL 並執行。

### Block 尺寸（from STEP）

| | Upper Block | Lower Block |
|--|---|---|
| 外形 | 25 × 22 × 10 mm | 22 × 22 × 10 mm |
| L 型截面 Part 1 | side -0.25~12.75, up ±11 | side 2~9, up ±11 |
| L 型截面 Part 2 | side -12.25~-0.25, up ±5 | side -13~2, up ±5 |
| STEP 來源 | `upper_block.STEP` | `lower_block.STEP` |
| Setting 參考 | `upper_block_setting.STEP` | `lower_block_setting.STEP` |

### 上下層安裝邏輯不同

```
Upper pole (35°傾斜):          Lower pole (5.71°傾斜):
pole 從 block 底面進入           pole 從 block 側面穿過

    ┌──────────┐ outer          ┌──────────┐
    │          │                │  ●═══════╪═ pole (幾乎水平)
    │  ● end   │                │  pole 在  │
    │  ╱       │                │  block    │
    │ ╱ 7mm    │                │  中央     │
    ├╱─────────┤ entry          └──────────┘
    ╱ pole

Block Z:                        Block Z:
  bottom = entry_z              center = pole_tail_z
  top = entry_z + 10mm          ±5mm (居中)

Block XY 中心:                  Block XY 中心:
  = pole 軸在 outer face         = pole 尾端 XY
```

### Block 建模方法

- **不使用 LOCAL CS**（已知會造成位置錯誤）
- 用 **global 座標算 8 角點 + V 指令**建每個 sub-block
- L 型截面 = 2 個矩形 VADD 合併
- 寬邊朝 workspace（XY 方向用 azimuth+180° 旋轉）

### APDL 注意事項（Block 專用）

| # | 陷阱 | 解法 |
|---|---|---|
| 1 | CSKP + LOCAL CS 建 BLOCK 位置會錯 | 用 global 座標 V 指令 |
| 2 | Upper/Lower 安裝邏輯不同 | Upper: 從底面進入; Lower: 從側面穿過，居中 |
| 3 | STEP 截面 slot 不在原點 | Upper 平移 +0.25mm, Lower 平移 -2mm |
| 4 | VADD 可能失敗（不影響幾何） | 45 volumes 正常（36 pole + 9 block） |

### SolidWorks 驗證清單（步驟 3）

- [ ] 6 個 block 都在 pole 尾端
- [ ] 上層 block：pole 從底面進入，pole 尾端在 block 內
- [ ] 下層 block：pole 從側面穿過，pole 在 block 垂直中央，不凸出
- [ ] Block 寬邊朝 workspace（朝 hexapole 中心方向）

---

## 步驟 4：安裝 Yoke（環形鐵板）

### 參數

| 參數 | 值 | 說明 |
|---|-----|---|
| YOKE_RI | 38.0 mm | 內徑（from 導磁鐵環.STEP） |
| YOKE_RO | 62.5 mm | 外徑（from 導磁鐵環.STEP） |
| YOKE_T | 2.0 mm | 厚度 |
| COIL_H | 14.0 mm | Block 頂到 Yoke 底的間距（coil 空間） |

### Z 位置鏈

```
fc_up_endz = fc_tz(P2) + POLE_TOTAL_LEN*sin(TILT_UP)     ! 上層 pole 尾端 Z
fc_up_blk_top = fc_up_endz + BLK_T/2                       ! 上層 block 頂
fc_yoke_zbot = fc_up_blk_top + COIL_H                      ! Yoke 底面
fc_yoke_ztop = fc_yoke_zbot + YOKE_T                       ! Yoke 頂面
```

### 建模方法

截面矩形 KP（R_inner, zbot）→（R_outer, zbot）→（R_outer, ztop）→（R_inner, ztop），加軸 KP 在 Z 軸上，VROTAT 360°, 4 divisions。

---

## 步驟 5：安裝 Guide Post（3 根）+ Upper Core（3 根）

### Guide Post（下層 P1, P3, P6）

| 參數 | 值 | 說明 |
|---|-----|---|
| GP_R | 4.0 mm | 半徑 |
| GP 頂端 Z | fc_yoke_zbot | 接 yoke 底面 |
| GP 底端 Z | fc_lo_endz - BLK_T/2 + 3.56 mm | lower block 底 + 3.56mm |
| GP XY | pole 尾端 XY | = fc_tx(i) + POLE_TOTAL_LEN*cos(TILT_DN)*cos(azim) |

建法：截面矩形 KP + VROTAT 360°, 4 divisions。3 根迴圈建立（P1, P3, P6）。

### Upper Core（上層 P2, P4, P5）

| 參數 | 值 | 說明 |
|---|-----|---|
| UC_R | 4.0 mm | 與 GP 相同 |
| UC 底端 Z | fc_up_blk_top2 = fc_up_endz + BLK_T/2 | upper block 頂面 |
| UC 頂端 Z | fc_yoke_zbot | 接 yoke 底面 |
| UC XY | pole 尾端 XY | = fc_tx(i) + POLE_TOTAL_LEN*cos(TILT_UP)*cos(azim) |

建法同 GP。3 根迴圈建立（P2, P4, P5）。

---

## 步驟 6：VADD + 空氣域 + VOVLAP + VGLUE

### 合併鋼件

```apdl
VADD, P51X    ! 所有 steel volumes → 1 個合併體
```

### 空氣域

| 域 | 幾何 | 參數 |
|----|---|---|
| 球形精細區 | SPHERE | R = 7.0 mm，原點 |
| 圓柱外空氣 | CYL4 | R = 80 mm, H = 80 mm，Z 中心在模型中點 |

### Boolean 操作

```apdl
VOVLAP, ALL         ! 重疊所有 volumes
NUMCMP, VOLU         ! 壓縮 volume 編號
VGLUE, 8, 1,2,3,4,5,6  ! Glue 鋼件(V8)與 tips(V1-6)
```

### 結果：9 Volumes

| Volume | 內容 | 材料 |
|---|---|---|
| V1-V6 | 6 根 pole tip（球內鐵） | MAT 2 (μr=280) |
| V7 | 球內空氣 | MAT 1 (μr=1) |
| V8 | 鋼主體（yoke + GP + cores + blocks + pole 外段） | MAT 2 (μr=280) |
| V9 | 圓柱外空氣 | MAT 3 (μr=1) |

---

## 步驟 7：材料 + Mesh + SOURC36 + 求解

### 材料與元素

```apdl
ET, 1, SOLID96       ! 磁純量勢元素
ET, 2, SOURC36       ! 電流源元素
MP, MURX, 1, 1       ! V7: 球內空氣
MP, MURX, 2, 280     ! V1-6, V8: 1018 鋼
MP, MURX, 3, 1       ! V9: 外空氣
```

### 分區 Mesh

| 區域 | Volumes | ESIZE | 說明 |
|---|---|---|---|
| Pole tips | V1-V6 | 0.3 mm | 最細（尖端需高解析） |
| 球內空氣 | V7 | 0.3 mm | 細（WP 區域） |
| 鋼主體 | V8 | 1.5 mm | 中等 |
| 外空氣 | V9 | 4.0 mm | 粗 |

目標：~2-3M elements。

### SOURC36 Coil 定義

| 參數 | 值 | 說明 |
|---|-----|---|
| TURNS | 70 | 匝數 |
| COIL_MEAN_R | 11.0 mm | (R_in=10 + R_out=12) / 2 |
| COIL_DY | 2.0 mm | R_out - R_in = 12 - 10 |
| COIL_DZ | 15.0 mm | 高度 |
| Coil 位置 Z | block_top + COIL_DZ/2 | 貼在 block 正上方 |
| Coil XY | pole 尾端 XY | 跟 GP/UC 相同 |
| 繞向 | 順時針（N1/N2 swap） | flux 向 -Z（toward block） |

Real constants：`R, i, 1, TURNS*CURR_ARRAY(i), COIL_DY, COIL_DZ`

CURR_ARRAY：每個檔案只激發 1 個 coil（coilN 檔 → CURR_ARRAY(N)=1，其餘=0）。

### 邊界條件

```apdl
! 圓柱頂面 MAG=0
NSEL, S, LOC, Z, z_top ± 1e-5
D, ALL, MAG, 0
! 圓柱底面 MAG=0
NSEL, S, LOC, Z, z_bot ± 1e-5
D, ALL, MAG, 0
! 圓柱側面 MAG=0 (用 LOCAL cylindrical CS)
LOCAL, 99, 1, 0, 0, 0
NSEL, S, LOC, X, AIR_CYL_R*0.99, AIR_CYL_R*1.01
D, ALL, MAG, 0
```

### 求解

```apdl
magsolv, 3, , , , , 1    ! DSP 方法
```

### SolidWorks 驗證清單（步驟 7 前）

- [ ] 9 volumes 正確（V1-6 tips, V7 sphere air, V8 steel, V9 cyl air）
- [ ] 材料指定正確（VATT）
- [ ] Mesh 完成無 error
- [ ] SOURC36 nodes 在正確位置（block 上方）
- [ ] MAG=0 BC 在外表面

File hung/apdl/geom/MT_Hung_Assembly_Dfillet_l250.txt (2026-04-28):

! =======================================
! MT_Hung_Assembly_Dfillet_l250.txt
! [MODIFIED for l-sensitivity study] l (=R_sphere) halved: 0.5 -> 0.25 mm
! 基底：MT_Hung_Assembly_Dfillet.txt（D-shape + 40 um tip fillet）
! 上層 (P2, P4, P5)：相對水平往上傾斜 35°
! 下層 (P1, P3, P6)：相對水平往下傾斜 5.71°
! R_sphere = 0.25mm（原 0.5mm 減半），方位角 120° 等距, magic angle
! Pole 尺寸來自 Mag_Pole_Bottom.STEP（未動）
! =======================================

/CWD,'G:\my_workspace\code\magnetic-tweezers-sim\hung\IGES'

/PREP7
*afun, DEG
BTOL, 1e-5
! [MODIFIED] SolidWorks 讀 IGES 固定當英寸 → 內部用英寸建模
! SolidWorks 匯入後自動 ×25.4 → 顯示為正確 mm 值
MM = 1.0/25.4                 ! [ADDED] 1mm = 0.03937 inches

! ===== Pole 尺寸 (from Mag_Pole_Bottom.STEP) =====
POLE_R         = 3.175*MM     ! [MODIFIED] 圓柱半徑
POLE_CONE_LEN  = 15.875*MM    ! [MODIFIED] 錐段長度
POLE_TOTAL_LEN = 43.0*MM      ! [MODIFIED] 總長
POLE_FLAT_LEN  = 28.0*MM      ! [MODIFIED] 削平長度

! [MODIFIED] Tip fillet 80 µm diameter = 40 µm radius (與 sim 腳本 + Long 2016 一致)
POLE_TIP_R    = 0.040*MM
PCH           = sqrt(POLE_CONE_LEN*POLE_CONE_LEN + POLE_R*POLE_R)
FANG1         = acos(POLE_R/PCH)
FANG2         = 90 - FANG1
LFIL          = POLE_CONE_LEN*POLE_TIP_R/POLE_R
PTC           = LFIL/cos(FANG2)
PCN2          = LFIL*cos(FANG2)
PTR2          = POLE_TIP_R*cos(FANG2)
FDROP         = PTC - POLE_TIP_R
FPROT         = PCN2 - FDROP
JUNC_X        = POLE_CONE_LEN - FDROP    ! cone-cyl 接點 X (was POLE_CONE_LEN)

! ===== 球面幾何 =====
R_sphere = 0.25*MM            ! [MODIFIED for l-sensitivity] l 減半：0.5mm -> 0.25mm
fc_theta = 54.74              ! [ADDED] magic angle (極角)
fc_h = cos(fc_theta)*R_sphere      ! [MODIFIED] 上層平面高度 (乘號前後不能有空格!)
fc_r = sin(fc_theta)*R_sphere      ! [MODIFIED] 上層圓半徑

TILT_UP = 35.0                ! [ADDED] 上層傾斜角 (度)
TILT_DN = 5.71                ! [ADDED] 下層傾斜角 (度)

! ===== 6 根 pole 定義 =====
! [MODIFIED] ANSYS 座標對齊 measured 座標系：ANSYS +X = X_m = P1 方向
! 索引 1-6 = P1-P6
! 逆時針：P1(0°) P5(60°) P3(120°) P2(180°) P6(240°) P4(300°)
*dim, fc_tx, , 6
*dim, fc_ty, , 6
*dim, fc_tz, , 6
*dim, fc_ia, , 6              ! incline (正=上, 負=下)
*dim, fc_ra, , 6              ! azimuth (outward 方向, = measured 方位角)

! --- P1 (lower, 0°) ---
fc_tx(1) = fc_r
fc_ty(1) = 0
fc_tz(1) = -fc_h
fc_ia(1) = -TILT_DN
fc_ra(1) = 0

! --- P5 (upper, 60°) ---
fc_tx(5) = cos(60)*fc_r
fc_ty(5) = sin(60)*fc_r
fc_tz(5) = fc_h
fc_ia(5) = TILT_UP
fc_ra(5) = 60

! --- P3 (lower, 120°) ---
fc_tx(3) = cos(120)*fc_r
fc_ty(3) = sin(120)*fc_r
fc_tz(3) = -fc_h
fc_ia(3) = -TILT_DN
fc_ra(3) = 120

! --- P2 (upper, 180°) ---
fc_tx(2) = cos(180)*fc_r
fc_ty(2) = sin(180)*fc_r
fc_tz(2) = fc_h
fc_ia(2) = TILT_UP
fc_ra(2) = 180

! --- P6 (lower, 240°) ---
fc_tx(6) = cos(240)*fc_r
fc_ty(6) = sin(240)*fc_r
fc_tz(6) = -fc_h
fc_ia(6) = -TILT_DN
fc_ra(6) = 240

! --- P4 (upper, 300°) ---
fc_tx(4) = cos(300)*fc_r
fc_ty(4) = sin(300)*fc_r
fc_tz(4) = fc_h
fc_ia(4) = TILT_UP
fc_ra(4) = 300

! ===== 建立 6 根 pole（兩段式：前段 D 型 + 後段全圓）=====
*do, fc_pi, 1, 6, 1

    fc_incl = fc_ia(fc_pi)
    fc_azim = fc_ra(fc_pi)

    ! --- 方向向量 ---
    fc_ax = cos(fc_incl)*cos(fc_azim)
    fc_ay = cos(fc_incl)*sin(fc_azim)
    fc_az = sin(fc_incl)

    ! [MODIFIED] 截面偏移方向：決定削平面朝向
    ! Upper pole: -side_perp → VROTAT 180° 保留下半 → 削平面朝上
    ! Lower pole: +side_perp → VROTAT 180° 保留上半 → 削平面朝下（轉 180°）
    *if, fc_incl, GE, 0, THEN
        fc_nsx = -sin(fc_azim)
        fc_nsy = cos(fc_azim)
    *else
        fc_nsx = sin(fc_azim)
        fc_nsy = -cos(fc_azim)
    *endif

    ! --- Numbering ---
    *get, KP_NUM, KP, , NUM, MAX
    *if, KP_NUM, LT, 1, THEN
        KP_NUM = 0
    *endif
    KP_START = KP_NUM + 1
    NUMSTR, KP, KP_START

    *get, LI_NUM, LINE, , NUM, MAX
    *if, LI_NUM, LT, 1, THEN
        LI_NUM = 0
    *endif
    LI_START = LI_NUM + 1
    NUMSTR, LINE, LI_START

    ! --- Tip 位置 ---
    p1x = fc_tx(fc_pi)
    p1y = fc_ty(fc_pi)
    p1z = fc_tz(fc_pi)

    ! --- 軸上關鍵位置 ---
    ! 削平交界（tip 起 28mm）
    fc_fx = p1x + POLE_FLAT_LEN*fc_ax
    fc_fy = p1y + POLE_FLAT_LEN*fc_ay
    fc_fz = p1z + POLE_FLAT_LEN*fc_az
    ! 後端（tip 起 43mm）
    fc_ex = p1x + POLE_TOTAL_LEN*fc_ax
    fc_ey = p1y + POLE_TOTAL_LEN*fc_ay
    fc_ez = p1z + POLE_TOTAL_LEN*fc_az

    ! ==========================================
    ! [MODIFIED] 前段：tip → 28mm（D 型，VROTAT 180°）+ 40µm fillet
    ! ==========================================
    ! KP+0: foremost (= 原 tip 位置, fillet 最前端)
    ! KP+1: 切線點 (cone 與 fillet 相切點，偏移 -side_perp)
    ! KP+2: 錐-柱交界 (用 JUNC_X，偏移 -side_perp)
    ! KP+3: 削平交界（偏移 -side_perp）
    ! KP+4: 削平交界（軸上）
    ! KP+5: 後端（軸上，僅作 VROTAT 軸用）
    ! KP+6: fillet 球心 (沿 +pole_axis 距 foremost = POLE_TIP_R)

    K, KP_START,   p1x, p1y, p1z
    K, KP_START+1, p1x + FPROT*fc_ax + PTR2*fc_nsx, p1y + FPROT*fc_ay + PTR2*fc_nsy, p1z + FPROT*fc_az
    K, KP_START+2, p1x + JUNC_X*fc_ax + POLE_R*fc_nsx, p1y + JUNC_X*fc_ay + POLE_R*fc_nsy, p1z + JUNC_X*fc_az
    K, KP_START+3, fc_fx + POLE_R*fc_nsx, fc_fy + POLE_R*fc_nsy, fc_fz
    K, KP_START+4, fc_fx, fc_fy, fc_fz
    K, KP_START+5, fc_ex, fc_ey, fc_ez
    K, KP_START+6, p1x + POLE_TIP_R*fc_ax, p1y + POLE_TIP_R*fc_ay, p1z + POLE_TIP_R*fc_az

    LARC, KP_START, KP_START+1, KP_START+6, POLE_TIP_R
    L, KP_START+1, KP_START+2
    L, KP_START+2, KP_START+3
    L, KP_START+3, KP_START+4
    L, KP_START+4, KP_START

    *get, AR_NUM, AREA, , NUM, MAX
    *if, AR_NUM, LT, 1, THEN
        AR_NUM = 0
    *endif
    AR_START = AR_NUM + 1
    NUMSTR, AREA, AR_START
    AL, LI_START, LI_START+1, LI_START+2, LI_START+3, LI_START+4

    VROTAT, AR_START, ,,,, , KP_START, KP_START+5, 180, 2

    ALLSEL, ALL

    ! ==========================================
    ! [ADDED] 後段：28mm → 43mm（全圓，VROTAT 360°）
    ! 用獨立 KP 避免共用問題
    ! ==========================================
    *get, KP_NUM, KP, , NUM, MAX
    KP_START2 = KP_NUM + 1
    NUMSTR, KP, KP_START2

    *get, LI_NUM, LINE, , NUM, MAX
    LI_START2 = LI_NUM + 1
    NUMSTR, LINE, LI_START2

    ! KP+0: 削平交界（軸上）— 獨立 KP
    ! KP+1: 削平交界（偏移 -side_perp）— 獨立 KP
    ! KP+2: 後端（偏移 -side_perp）
    ! KP+3: 後端（軸上）— 獨立 KP

    K, KP_START2,   fc_fx, fc_fy, fc_fz
    K, KP_START2+1, fc_fx + POLE_R*fc_nsx, fc_fy + POLE_R*fc_nsy, fc_fz
    K, KP_START2+2, fc_ex + POLE_R*fc_nsx, fc_ey + POLE_R*fc_nsy, fc_ez
    K, KP_START2+3, fc_ex, fc_ey, fc_ez

    L, KP_START2, KP_START2+1
    L, KP_START2+1, KP_START2+2
    L, KP_START2+2, KP_START2+3
    L, KP_START2+3, KP_START2

    *get, AR_NUM, AREA, , NUM, MAX
    AR_START2 = AR_NUM + 1
    NUMSTR, AREA, AR_START2
    AL, LI_START2, LI_START2+1, LI_START2+2, LI_START2+3

    VROTAT, AR_START2, ,,,, , KP_START2, KP_START2+3, , 4

    ALLSEL, ALL

    *msg, INFO, fc_pi
     Pole P%I built (D-shape + round)

*enddo

! ===== [ADDED] 安裝 block =====
! Upper block: 25×22×10mm, L型截面, 伸入7mm
! Lower block: 22×22×10mm, L型截面, 伸入4.5mm
! 寬邊朝 workspace, block 厚度沿 pole 軸

PENE_UP = 7.0*MM              ! 上層伸入量
PENE_DN = 4.5*MM              ! 下層伸入量
BLK_T   = 10.0*MM             ! block 厚度 (兩者相同)

*do, fc_pi, 1, 6, 1

    fc_incl = fc_ia(fc_pi)
    fc_azim = fc_ra(fc_pi)

    ! 軸方向
    fc_ax = cos(fc_incl)*cos(fc_azim)
    fc_ay = cos(fc_incl)*sin(fc_azim)
    fc_az = sin(fc_incl)

    ! up_perp (垂直軸,朝上)
    fc_ux = -sin(fc_incl)*cos(fc_azim)
    fc_uy = -sin(fc_incl)*sin(fc_azim)
    fc_uz = cos(fc_incl)

    ! side_perp (側向)
    fc_sx = sin(fc_azim)
    fc_sy = -cos(fc_azim)

    ! Tip 位置
    p1x = fc_tx(fc_pi)
    p1y = fc_ty(fc_pi)
    p1z = fc_tz(fc_pi)

    ! 判斷上下層 → 決定伸入量和 block 尺寸
    *if, fc_incl, GE, 0, THEN
        ! Upper pole → upper block (25×22×10)
        fc_pene = PENE_UP
        ! L型截面 (STEP coords → local: STEP_X=side, STEP_Y=up)
        ! Part1: side -0.5~12.5, up -11~11 (main body)
        ! Part2: side -12.5~-0.5, up -5~5 (extension)
        ! [MODIFIED] 平移 +0.25mm 讓 slot 中心對齊 pole 軸
        fc_s1a = -0.25*MM
        fc_s1b = 12.75*MM
        fc_u1a = -11.0*MM
        fc_u1b = 11.0*MM
        fc_s2a = -12.25*MM
        fc_s2b = -0.25*MM
        fc_u2a = -5.0*MM
        fc_u2b = 5.0*MM
    *else
        ! Lower pole → lower block (22×22×10)
        ! Part1: side 0~11, up -11~11 (main body)
        ! Part2: side -11~0, up -5~5 (extension)
        fc_pene = PENE_DN
        ! [MODIFIED] 平移 -2mm 讓 slot 中心(x=2)對齊 pole 軸
        fc_s1a = 2.0*MM       ! 4-2=2
        fc_s1b = 9.0*MM       ! 11-2=9
        fc_u1a = -11.0*MM
        fc_u1b = 11.0*MM
        fc_s2a = -13.0*MM     ! -11-2=-13
        fc_s2b = 2.0*MM       ! 4-2=2
        fc_u2a = -5.0*MM
        fc_u2b = 5.0*MM
    *endif

    ! Block 起點（沿 pole 軸，從 tip 算）
    fc_bstart = POLE_TOTAL_LEN - fc_pene

    ! [MODIFIED] Block 水平, global 座標, 不用 LOCAL CS
    ! Pole 尾端
    fc_endx = p1x + POLE_TOTAL_LEN*fc_ax
    fc_endy = p1y + POLE_TOTAL_LEN*fc_ay
    fc_endz = p1z + POLE_TOTAL_LEN*fc_az

    ! Entry point (workspace face, pole 尾端往回 PENE)
    fc_entx = fc_endx - fc_pene*fc_ax
    fc_enty = fc_endy - fc_pene*fc_ay
    fc_entz = fc_endz - fc_pene*fc_az

    ! Block Z 範圍 + XY 中心
    *if, fc_incl, GE, 0, THEN
        ! Upper: entry=bottom, outer=top
        fc_zbot = fc_entz
        fc_ztop = fc_entz + BLK_T
        ! Block 中心 = pole 軸在 outer face (top) 的 XY
        ! outer = entry + (BLK_T/sin(tilt))*axis
        fc_dt = BLK_T/sin(TILT_UP)
        fc_cx = fc_entx + fc_dt*fc_ax
        fc_cy = fc_enty + fc_dt*fc_ay
    *else
        ! Lower: pole 從側面穿過 block → block 垂直居中在 pole 軸上
        fc_zbot = fc_endz - BLK_T/2
        fc_ztop = fc_endz + BLK_T/2
        ! Block 中心 = pole 尾端 XY
        fc_cx = fc_endx
        fc_cy = fc_endy
    *endif

    ! XY 方向向量 (水平面, 朝 workspace = azim+180°)
    fc_twx = -cos(fc_azim)
    fc_twy = -sin(fc_azim)
    fc_sdx = sin(fc_azim)
    fc_sdy = -cos(fc_azim)

    ! --- Block Part 1: 8 角點 (global) ---
    *get, KP_NUM, KP, , NUM, MAX
    *if, KP_NUM, LT, 1, THEN
        KP_NUM = 0
    *endif
    fc_bkp = KP_NUM + 1
    NUMSTR, KP, fc_bkp

    ! Bottom face (z=fc_zbot), 4 corners: (s1a,u1a) (s1b,u1a) (s1b,u1b) (s1a,u1b)
    K,fc_bkp,  fc_cx+fc_s1a*fc_twx+fc_u1a*fc_sdx, fc_cy+fc_s1a*fc_twy+fc_u1a*fc_sdy, fc_zbot
    K,fc_bkp+1,fc_cx+fc_s1b*fc_twx+fc_u1a*fc_sdx, fc_cy+fc_s1b*fc_twy+fc_u1a*fc_sdy, fc_zbot
    K,fc_bkp+2,fc_cx+fc_s1b*fc_twx+fc_u1b*fc_sdx, fc_cy+fc_s1b*fc_twy+fc_u1b*fc_sdy, fc_zbot
    K,fc_bkp+3,fc_cx+fc_s1a*fc_twx+fc_u1b*fc_sdx, fc_cy+fc_s1a*fc_twy+fc_u1b*fc_sdy, fc_zbot
    ! Top face (z=fc_ztop)
    K,fc_bkp+4,fc_cx+fc_s1a*fc_twx+fc_u1a*fc_sdx, fc_cy+fc_s1a*fc_twy+fc_u1a*fc_sdy, fc_ztop
    K,fc_bkp+5,fc_cx+fc_s1b*fc_twx+fc_u1a*fc_sdx, fc_cy+fc_s1b*fc_twy+fc_u1a*fc_sdy, fc_ztop
    K,fc_bkp+6,fc_cx+fc_s1b*fc_twx+fc_u1b*fc_sdx, fc_cy+fc_s1b*fc_twy+fc_u1b*fc_sdy, fc_ztop
    K,fc_bkp+7,fc_cx+fc_s1a*fc_twx+fc_u1b*fc_sdx, fc_cy+fc_s1a*fc_twy+fc_u1b*fc_sdy, fc_ztop

    V,fc_bkp,fc_bkp+1,fc_bkp+2,fc_bkp+3,fc_bkp+4,fc_bkp+5,fc_bkp+6,fc_bkp+7

    ! --- Block Part 2: 8 角點 ---
    *get, KP_NUM, KP, , NUM, MAX
    fc_bkp2 = KP_NUM + 1
    NUMSTR, KP, fc_bkp2

    K,fc_bkp2,  fc_cx+fc_s2a*fc_twx+fc_u2a*fc_sdx, fc_cy+fc_s2a*fc_twy+fc_u2a*fc_sdy, fc_zbot
    K,fc_bkp2+1,fc_cx+fc_s2b*fc_twx+fc_u2a*fc_sdx, fc_cy+fc_s2b*fc_twy+fc_u2a*fc_sdy, fc_zbot
    K,fc_bkp2+2,fc_cx+fc_s2b*fc_twx+fc_u2b*fc_sdx, fc_cy+fc_s2b*fc_twy+fc_u2b*fc_sdy, fc_zbot
    K,fc_bkp2+3,fc_cx+fc_s2a*fc_twx+fc_u2b*fc_sdx, fc_cy+fc_s2a*fc_twy+fc_u2b*fc_sdy, fc_zbot
    K,fc_bkp2+4,fc_cx+fc_s2a*fc_twx+fc_u2a*fc_sdx, fc_cy+fc_s2a*fc_twy+fc_u2a*fc_sdy, fc_ztop
    K,fc_bkp2+5,fc_cx+fc_s2b*fc_twx+fc_u2a*fc_sdx, fc_cy+fc_s2b*fc_twy+fc_u2a*fc_sdy, fc_ztop
    K,fc_bkp2+6,fc_cx+fc_s2b*fc_twx+fc_u2b*fc_sdx, fc_cy+fc_s2b*fc_twy+fc_u2b*fc_sdy, fc_ztop
    K,fc_bkp2+7,fc_cx+fc_s2a*fc_twx+fc_u2b*fc_sdx, fc_cy+fc_s2a*fc_twy+fc_u2b*fc_sdy, fc_ztop

    V,fc_bkp2,fc_bkp2+1,fc_bkp2+2,fc_bkp2+3,fc_bkp2+4,fc_bkp2+5,fc_bkp2+6,fc_bkp2+7

    ! VADD
    *get, fc_bv2, VOLU, 0, NUM, MAX
    fc_bv1 = fc_bv2 - 1
    VADD, fc_bv1, fc_bv2

    ALLSEL, ALL

    *msg, INFO, fc_pi
     Block for P%I built

*enddo

! ===== [ADDED] 安裝線圈 =====
! 線圈軸垂直 Z, XY = block 中心
! 簡化繞線區: R_inner=6, R_outer=10, height=14mm
! 上層: z = block_bottom ~ block_bottom+17mm (assembly 關係)
! 下層: z = block_bottom-17mm ~ block_bottom

COIL_RI = 6.0*MM              ! 繞線區內徑
COIL_RO = 10.0*MM             ! 繞線區外徑
COIL_H  = 14.0*MM             ! 繞線區高度

*do, fc_pi, 1, 6, 1

    fc_incl = fc_ia(fc_pi)
    fc_azim = fc_ra(fc_pi)

    fc_ax = cos(fc_incl)*cos(fc_azim)
    fc_ay = cos(fc_incl)*sin(fc_azim)
    fc_az = sin(fc_incl)

    p1x = fc_tx(fc_pi)
    p1y = fc_ty(fc_pi)
    p1z = fc_tz(fc_pi)

    ! Block 中心 (跟步驟 3 一樣)
    fc_endx = p1x + POLE_TOTAL_LEN*fc_ax
    fc_endy = p1y + POLE_TOTAL_LEN*fc_ay
    fc_endz = p1z + POLE_TOTAL_LEN*fc_az

    *if, fc_incl, GE, 0, THEN
        fc_pene = PENE_UP
        fc_entx = fc_endx - fc_pene*fc_ax
        fc_enty = fc_endy - fc_pene*fc_ay
        fc_entz = fc_endz - fc_pene*fc_az
        fc_ztop_blk = fc_entz + BLK_T
        fc_dt = BLK_T/sin(TILT_UP)
        fc_cx = fc_entx + fc_dt*fc_ax
        fc_cy = fc_enty + fc_dt*fc_ay
    *else
        fc_cx = fc_endx
        fc_cy = fc_endy
        fc_ztop_blk = fc_endz + BLK_T/2
    *endif
    ! Coil Z 在 block 上方
    fc_cz1 = fc_ztop_blk
    fc_cz2 = fc_ztop_blk + COIL_H

    ! 截面 KP + 軸 KP
    *get, KP_NUM, KP, , NUM, MAX
    *if, KP_NUM, LT, 1, THEN
        KP_NUM = 0
    *endif
    fc_ckp = KP_NUM + 1
    NUMSTR, KP, fc_ckp

    K, fc_ckp,   fc_cx+COIL_RI, fc_cy, fc_cz1
    K, fc_ckp+1, fc_cx+COIL_RO, fc_cy, fc_cz1
    K, fc_ckp+2, fc_cx+COIL_RO, fc_cy, fc_cz2
    K, fc_ckp+3, fc_cx+COIL_RI, fc_cy, fc_cz2
    K, fc_ckp+4, fc_cx, fc_cy, fc_cz1
    K, fc_ckp+5, fc_cx, fc_cy, fc_cz2

    *get, LI_NUM, LINE, , NUM, MAX
    *if, LI_NUM, LT, 1, THEN
        LI_NUM = 0
    *endif
    fc_cli = LI_NUM + 1
    NUMSTR, LINE, fc_cli
    L,fc_ckp,fc_ckp+1
    L,fc_ckp+1,fc_ckp+2
    L,fc_ckp+2,fc_ckp+3
    L,fc_ckp+3,fc_ckp
    *get, AR_NUM, AREA, , NUM, MAX
    fc_car = AR_NUM + 1
    NUMSTR, AREA, fc_car
    AL,fc_cli,fc_cli+1,fc_cli+2,fc_cli+3
    VROTAT,fc_car,,,,,,fc_ckp+4,fc_ckp+5,,4

    ALLSEL, ALL

    *msg, INFO, fc_pi
     Coil for P%I built

*enddo

! ===== [ADDED] 安裝 Yoke =====
! 環形板, 中心在原點, 軸 Z, 在上層 coil 頂面上方
! R_inner=40, R_outer=52, 厚度 2mm

YOKE_RI = 38.0*MM             ! [MODIFIED] 內徑縮小讓導柱不露出
YOKE_RO = 62.5*MM             ! [MODIFIED] 從導磁鐵環.STEP 提取
YOKE_T  = 2.0*MM

! 上層 coil top z: 需要從上層 block 計算
! 上層 entry_z 已在 coil 迴圈中算過, 重新算一次
! 所有上層 pole 的 fc_endz 相同, 取 P2 的
fc_up_endz = fc_tz(2) + POLE_TOTAL_LEN*sin(TILT_UP)
fc_up_entz = fc_up_endz - PENE_UP*sin(TILT_UP)
fc_up_blk_top = fc_up_entz + BLK_T
fc_yoke_zbot = fc_up_blk_top + COIL_H
fc_yoke_ztop = fc_yoke_zbot + YOKE_T

! Yoke 截面 KP (矩形: R_inner~R_outer, zbot~ztop)
*get, KP_NUM, KP, , NUM, MAX
*if, KP_NUM, LT, 1, THEN
    KP_NUM = 0
*endif
fc_ykp = KP_NUM + 1
NUMSTR, KP, fc_ykp

K, fc_ykp,   YOKE_RI, 0, fc_yoke_zbot
K, fc_ykp+1, YOKE_RO, 0, fc_yoke_zbot
K, fc_ykp+2, YOKE_RO, 0, fc_yoke_ztop
K, fc_ykp+3, YOKE_RI, 0, fc_yoke_ztop
! 軸 KP (Z 軸, 通過原點)
K, fc_ykp+4, 0, 0, fc_yoke_zbot
K, fc_ykp+5, 0, 0, fc_yoke_ztop

*get, LI_NUM, LINE, , NUM, MAX
*if, LI_NUM, LT, 1, THEN
    LI_NUM = 0
*endif
fc_yli = LI_NUM + 1
NUMSTR, LINE, fc_yli

L, fc_ykp, fc_ykp+1
L, fc_ykp+1, fc_ykp+2
L, fc_ykp+2, fc_ykp+3
L, fc_ykp+3, fc_ykp

*get, AR_NUM, AREA, , NUM, MAX
*if, AR_NUM, LT, 1, THEN
    AR_NUM = 0
*endif
fc_yar = AR_NUM + 1
NUMSTR, AREA, fc_yar
AL, fc_yli, fc_yli+1, fc_yli+2, fc_yli+3

VROTAT, fc_yar, ,,,, , fc_ykp+4, fc_ykp+5, , 4

ALLSEL, ALL

*msg, INFO
 Yoke built

! ===== [ADDED] 安裝磁場導柱 =====
! 3 根, 連接 yoke → 下層 block, 穿過上層 coil 中心孔
! 簡化為圓柱 R=4mm, 從 lower_block_top 到 yoke_bottom
! XY = 下層 block 中心 (P1, P3, P6)

GP_R = 4.0*MM                 ! 導柱半徑 (取最大截面)
GP_H = 46.0*MM                ! 導柱總高 46mm
GP_YOKE_R = 57.5*MM           ! [ADDED] 導柱在 yoke 上的徑向位置 (螺絲孔)

! 下層 block top z (所有下層相同)
fc_lo_endz = fc_tz(1) + POLE_TOTAL_LEN*sin(-TILT_DN)
fc_lo_blk_top = fc_lo_endz + BLK_T/2

! 下層 pole 索引: P1=1, P3=3, P6=6
*dim, fc_gpi, , 3
fc_gpi(1) = 1
fc_gpi(2) = 3
fc_gpi(3) = 6

*do, fc_gi, 1, 3, 1
    fc_idx = fc_gpi(fc_gi)
    fc_azim = fc_ra(fc_idx)

    ! 導柱 XY = 下層 block 中心
    fc_ax = cos(-TILT_DN)*cos(fc_azim)
    fc_ay = cos(-TILT_DN)*sin(fc_azim)
    fc_gcx = fc_tx(fc_idx) + POLE_TOTAL_LEN*fc_ax
    fc_gcy = fc_ty(fc_idx) + POLE_TOTAL_LEN*fc_ay

    ! 導柱 Z: lower_block_top → yoke_bottom
    ! [MODIFIED] 導柱頂端接 yoke 底面，向下延伸 46mm
    fc_gz2 = fc_yoke_zbot             ! 導柱頂 = yoke 底面
    fc_gz1 = fc_yoke_zbot - GP_H      ! 導柱底 = yoke 底 - 46mm

    ! 截面 KP (矩形 0~R, z1~z2) + 軸 KP
    *get, KP_NUM, KP, , NUM, MAX
    *if, KP_NUM, LT, 1, THEN
        KP_NUM = 0
    *endif
    fc_gkp = KP_NUM + 1
    NUMSTR, KP, fc_gkp

    K, fc_gkp,   fc_gcx+GP_R, fc_gcy, fc_gz1
    K, fc_gkp+1, fc_gcx+GP_R, fc_gcy, fc_gz2
    K, fc_gkp+2, fc_gcx,      fc_gcy, fc_gz2
    K, fc_gkp+3, fc_gcx,      fc_gcy, fc_gz1

    *get, LI_NUM, LINE, , NUM, MAX
    *if, LI_NUM, LT, 1, THEN
        LI_NUM = 0
    *endif
    fc_gli = LI_NUM + 1
    NUMSTR, LINE, fc_gli

    L, fc_gkp, fc_gkp+1
    L, fc_gkp+1, fc_gkp+2
    L, fc_gkp+2, fc_gkp+3
    L, fc_gkp+3, fc_gkp

    *get, AR_NUM, AREA, , NUM, MAX
    *if, AR_NUM, LT, 1, THEN
        AR_NUM = 0
    *endif
    fc_gar = AR_NUM + 1
    NUMSTR, AREA, fc_gar
    AL, fc_gli, fc_gli+1, fc_gli+2, fc_gli+3

    ! VROTAT 繞垂直軸 (通過導柱中心)
    VROTAT, fc_gar, ,,,, , fc_gkp+2, fc_gkp+3, , 4

    ALLSEL, ALL

    *msg, INFO, fc_gi
     Guide post %I built

*enddo

! ===== [ADDED] 上層 Core =====
! 3 根, 連接 yoke → 上層 block, R=4mm
! XY = 上層 block 中心 (P2, P4, P5)

fc_up_blk_top2 = fc_up_entz + BLK_T

*dim, fc_upi, , 3
fc_upi(1) = 2
fc_upi(2) = 4
fc_upi(3) = 5

*do, fc_ui, 1, 3, 1
    fc_idx = fc_upi(fc_ui)
    fc_azim = fc_ra(fc_idx)

    ! 上層 core XY = 上層 block 中心
    fc_pene_tmp = PENE_UP
    fc_ax_tmp = cos(TILT_UP)*cos(fc_azim)
    fc_ay_tmp = cos(TILT_UP)*sin(fc_azim)
    fc_endx_tmp = fc_tx(fc_idx) + POLE_TOTAL_LEN*fc_ax_tmp
    fc_endy_tmp = fc_ty(fc_idx) + POLE_TOTAL_LEN*fc_ay_tmp
    fc_endz_tmp = fc_tz(fc_idx) + POLE_TOTAL_LEN*sin(TILT_UP)
    fc_entx_tmp = fc_endx_tmp - fc_pene_tmp*fc_ax_tmp
    fc_enty_tmp = fc_endy_tmp - fc_pene_tmp*fc_ay_tmp
    fc_dt_tmp = BLK_T/sin(TILT_UP)
    fc_ucx = fc_entx_tmp + fc_dt_tmp*fc_ax_tmp
    fc_ucy = fc_enty_tmp + fc_dt_tmp*fc_ay_tmp

    ! Core Z: 上層 block top → yoke bottom
    fc_ucz1 = fc_up_blk_top2
    fc_ucz2 = fc_yoke_zbot

    ! 截面 + 軸 KP
    *get, KP_NUM, KP, , NUM, MAX
    *if, KP_NUM, LT, 1, THEN
        KP_NUM = 0
    *endif
    fc_uckp = KP_NUM + 1
    NUMSTR, KP, fc_uckp

    K,fc_uckp,  fc_ucx+GP_R, fc_ucy, fc_ucz1
    K,fc_uckp+1,fc_ucx+GP_R, fc_ucy, fc_ucz2
    K,fc_uckp+2,fc_ucx,      fc_ucy, fc_ucz2
    K,fc_uckp+3,fc_ucx,      fc_ucy, fc_ucz1

    *get, LI_NUM, LINE, , NUM, MAX
    fc_ucli = LI_NUM + 1
    NUMSTR, LINE, fc_ucli
    L,fc_uckp,fc_uckp+1
    L,fc_uckp+1,fc_uckp+2
    L,fc_uckp+2,fc_uckp+3
    L,fc_uckp+3,fc_uckp

    *get, AR_NUM, AREA, , NUM, MAX
    fc_ucar = AR_NUM + 1
    NUMSTR, AREA, fc_ucar
    AL,fc_ucli,fc_ucli+1,fc_ucli+2,fc_ucli+3

    VROTAT,fc_ucar,,,,,,fc_uckp+2,fc_uckp+3,,4

    ALLSEL, ALL

    *msg, INFO, fc_ui
     Upper core %I built

*enddo

! ===== 整理與匯出 =====
CSYS, 0
NUMCMP, VOLU
NUMCMP, AREA
NUMCMP, LINE
NUMCMP, KP

*get, fc_nvf, VOLU, 0, NUM, MAX
*msg, INFO, fc_nvf
 Final: %I volumes

! [MODIFIED] commented out SAVE to prevent .db pollution in IGES folder
!**** SAVE, 'Full_Assembly_Dfillet_l250', 'db'

ALLSEL, ALL
IGESOUT, 'Full_Assembly_Dfillet_l250', 'iges'

! 匯出後手動修正 unit flag (不覆蓋原檔):
! cp Hung_SphereModel.iges Hung_SphereModel_inch.iges
! sed -i "s/,1.0,6,,/,1.0,1,,/" Hung_SphereModel_inch.iges

FINISH
! [ADDED] exit without auto-saving jobname.db - prevents pollution of IGES folder
/EXIT, NOSAV

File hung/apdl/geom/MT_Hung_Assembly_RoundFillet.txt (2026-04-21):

! =======================================
! MT_Hung_Assembly_RoundFillet.txt
! [MODIFIED] Geometry-only: full-round pole body + R=40um fillet tip
! [MODIFIED] Full hexapole assembly, exports Full_Assembly_round_filleted.iges for SolidWorks
! =======================================

/CWD,'C:\Users\pmero\Documents\Lab406\magnetic-tweezers-sim\hung\IGES'

/PREP7
*afun, DEG
BTOL, 1e-5
! SolidWorks reads IGES as inches -> build model in inches (x25.4 on import)
MM = 1.0/25.4                ! 1mm = 0.03937 inches

! ===== Pole 尺寸 =====
POLE_R         = 3.175*MM
POLE_CONE_LEN  = 15.875*MM
POLE_TOTAL_LEN = 43.0*MM

! ===== [MODIFIED] Tip fillet (80 µm 直徑 = 40 µm 半徑, 與龍飛一致) =====
POLE_TIP_R    = 0.040*MM
PCH           = sqrt(POLE_CONE_LEN*POLE_CONE_LEN + POLE_R*POLE_R)
FANG1         = acos(POLE_R/PCH)
FANG2         = 90 - FANG1
LFIL          = POLE_CONE_LEN*POLE_TIP_R/POLE_R
PTC           = LFIL/cos(FANG2)
PCN2          = LFIL*cos(FANG2)
PTR2          = POLE_TIP_R*cos(FANG2)
FDROP         = PTC - POLE_TIP_R
FPROT         = PCN2 - FDROP
JUNC_X        = POLE_CONE_LEN - FDROP    ! cone-cyl 接點 X (=15.793mm)

! ===== 球面幾何 =====
R_sphere = 0.5*MM             ! [MODIFIED] 球半徑
fc_theta = 54.74              ! [ADDED] magic angle (極角)
fc_h = cos(fc_theta)*R_sphere      ! [MODIFIED] 上層平面高度 (乘號前後不能有空格!)
fc_r = sin(fc_theta)*R_sphere      ! [MODIFIED] 上層圓半徑

TILT_UP = 35.0                ! [ADDED] 上層傾斜角 (度)
TILT_DN = 5.71                ! [ADDED] 下層傾斜角 (度)

! ===== 6 根 pole 定義 =====
! [MODIFIED] ANSYS 座標對齊 measured 座標系：ANSYS +X = X_m = P1 方向
! 索引 1-6 = P1-P6
! 逆時針：P1(0°) P5(60°) P3(120°) P2(180°) P6(240°) P4(300°)
*dim, fc_tx, , 6
*dim, fc_ty, , 6
*dim, fc_tz, , 6
*dim, fc_ia, , 6              ! incline (正=上, 負=下)
*dim, fc_ra, , 6              ! azimuth (outward 方向, = measured 方位角)

! --- P1 (lower, 0°) ---
fc_tx(1) = fc_r
fc_ty(1) = 0
fc_tz(1) = -fc_h
fc_ia(1) = -TILT_DN
fc_ra(1) = 0

! --- P5 (upper, 60°) ---
fc_tx(5) = cos(60)*fc_r
fc_ty(5) = sin(60)*fc_r
fc_tz(5) = fc_h
fc_ia(5) = TILT_UP
fc_ra(5) = 60

! --- P3 (lower, 120°) ---
fc_tx(3) = cos(120)*fc_r
fc_ty(3) = sin(120)*fc_r
fc_tz(3) = -fc_h
fc_ia(3) = -TILT_DN
fc_ra(3) = 120

! --- P2 (upper, 180°) ---
fc_tx(2) = cos(180)*fc_r
fc_ty(2) = sin(180)*fc_r
fc_tz(2) = fc_h
fc_ia(2) = TILT_UP
fc_ra(2) = 180

! --- P6 (lower, 240°) ---
fc_tx(6) = cos(240)*fc_r
fc_ty(6) = sin(240)*fc_r
fc_tz(6) = -fc_h
fc_ia(6) = -TILT_DN
fc_ra(6) = 240

! --- P4 (upper, 300°) ---
fc_tx(4) = cos(300)*fc_r
fc_ty(4) = sin(300)*fc_r
fc_tz(4) = fc_h
fc_ia(4) = TILT_UP
fc_ra(4) = 300

! ===== [MODIFIED] 建立 6 根全圓 pole（VROTAT 360°, 含 fillet）=====
*do, fc_pi, 1, 6, 1

    fc_incl = fc_ia(fc_pi)
    fc_azim = fc_ra(fc_pi)

    ! --- 方向向量 ---
    fc_ax = cos(fc_incl)*cos(fc_azim)
    fc_ay = cos(fc_incl)*sin(fc_azim)
    fc_az = sin(fc_incl)

    ! [MODIFIED] 全圓不需要條件翻轉，統一用 -sin/cos
    fc_nsx = -sin(fc_azim)
    fc_nsy = cos(fc_azim)

    ! --- Numbering ---
    *get, KP_NUM, KP, , NUM, MAX
    *if, KP_NUM, LT, 1, THEN
        KP_NUM = 0
    *endif
    KP_START = KP_NUM + 1
    NUMSTR, KP, KP_START

    *get, LI_NUM, LINE, , NUM, MAX
    *if, LI_NUM, LT, 1, THEN
        LI_NUM = 0
    *endif
    LI_START = LI_NUM + 1
    NUMSTR, LINE, LI_START

    ! --- Tip 位置 ---
    p1x = fc_tx(fc_pi)
    p1y = fc_ty(fc_pi)
    p1z = fc_tz(fc_pi)

    ! --- 後端（tip 起 43mm）---
    fc_ex = p1x + POLE_TOTAL_LEN*fc_ax
    fc_ey = p1y + POLE_TOTAL_LEN*fc_ay
    fc_ez = p1z + POLE_TOTAL_LEN*fc_az

    ! ==========================================
    ! [MODIFIED] 全圓截面 (fillet → cone → cylinder → end → axis)
    ! VROTAT 360° 繞 pole 軸, 4 segments
    ! ==========================================
    ! KP+0: foremost (tip, 軸上)
    ! KP+1: tangent point (fillet-cone 切點, 偏移 ns)
    ! KP+2: cone-cyl junction (偏移 ns)
    ! KP+3: far end (偏移 ns)
    ! KP+4: far end (軸上, VROTAT 軸端)
    ! KP+5: fillet center (沿軸, 距 tip = POLE_TIP_R)

    K, KP_START,   p1x, p1y, p1z
    K, KP_START+1, p1x + FPROT*fc_ax + PTR2*fc_nsx, p1y + FPROT*fc_ay + PTR2*fc_nsy, p1z + FPROT*fc_az
    K, KP_START+2, p1x + JUNC_X*fc_ax + POLE_R*fc_nsx, p1y + JUNC_X*fc_ay + POLE_R*fc_nsy, p1z + JUNC_X*fc_az
    K, KP_START+3, fc_ex + POLE_R*fc_nsx, fc_ey + POLE_R*fc_nsy, fc_ez
    K, KP_START+4, fc_ex, fc_ey, fc_ez
    K, KP_START+5, p1x + POLE_TIP_R*fc_ax, p1y + POLE_TIP_R*fc_ay, p1z + POLE_TIP_R*fc_az

    ! Lines: fillet arc + cone + cylinder + end face + axis
    LARC, KP_START, KP_START+1, KP_START+5, POLE_TIP_R
    L, KP_START+1, KP_START+2
    L, KP_START+2, KP_START+3
    L, KP_START+3, KP_START+4
    L, KP_START+4, KP_START

    ! Area
    *get, AR_NUM, AREA, , NUM, MAX
    *if, AR_NUM, LT, 1, THEN
        AR_NUM = 0
    *endif
    AR_START = AR_NUM + 1
    NUMSTR, AREA, AR_START
    AL, LI_START, LI_START+1, LI_START+2, LI_START+3, LI_START+4

    ! VROTAT 360° (全圓, 4 segments) 繞 tip → end 軸
    VROTAT, AR_START, ,,,, , KP_START, KP_START+4, , 4

    ALLSEL, ALL

    *msg, INFO, fc_pi
     Pole P%I built (full round + R=40um fillet)

*enddo

! ===== [ADDED] 安裝 block =====
! Upper block: 25×22×10mm, L型截面, 伸入7mm
! Lower block: 22×22×10mm, L型截面, 伸入4.5mm
! 寬邊朝 workspace, block 厚度沿 pole 軸

PENE_UP = 7.0*MM              ! 上層伸入量
PENE_DN = 4.5*MM              ! 下層伸入量
BLK_T   = 10.0*MM             ! block 厚度 (兩者相同)

*do, fc_pi, 1, 6, 1

    fc_incl = fc_ia(fc_pi)
    fc_azim = fc_ra(fc_pi)

    ! 軸方向
    fc_ax = cos(fc_incl)*cos(fc_azim)
    fc_ay = cos(fc_incl)*sin(fc_azim)
    fc_az = sin(fc_incl)

    ! up_perp (垂直軸,朝上)
    fc_ux = -sin(fc_incl)*cos(fc_azim)
    fc_uy = -sin(fc_incl)*sin(fc_azim)
    fc_uz = cos(fc_incl)

    ! side_perp (側向)
    fc_sx = sin(fc_azim)
    fc_sy = -cos(fc_azim)

    ! Tip 位置
    p1x = fc_tx(fc_pi)
    p1y = fc_ty(fc_pi)
    p1z = fc_tz(fc_pi)

    ! 判斷上下層 → 決定伸入量和 block 尺寸
    *if, fc_incl, GE, 0, THEN
        ! Upper pole → upper block (25×22×10)
        fc_pene = PENE_UP
        ! L型截面 (STEP coords → local: STEP_X=side, STEP_Y=up)
        ! Part1: side -0.5~12.5, up -11~11 (main body)
        ! Part2: side -12.5~-0.5, up -5~5 (extension)
        ! [MODIFIED] 平移 +0.25mm 讓 slot 中心對齊 pole 軸
        fc_s1a = -0.25*MM
        fc_s1b = 12.75*MM
        fc_u1a = -11.0*MM
        fc_u1b = 11.0*MM
        fc_s2a = -12.25*MM
        fc_s2b = -0.25*MM
        fc_u2a = -5.0*MM
        fc_u2b = 5.0*MM
    *else
        ! Lower pole → lower block (22×22×10)
        ! Part1: side 0~11, up -11~11 (main body)
        ! Part2: side -11~0, up -5~5 (extension)
        fc_pene = PENE_DN
        ! [MODIFIED] 平移 -2mm 讓 slot 中心(x=2)對齊 pole 軸
        fc_s1a = 2.0*MM       ! 4-2=2
        fc_s1b = 9.0*MM       ! 11-2=9
        fc_u1a = -11.0*MM
        fc_u1b = 11.0*MM
        fc_s2a = -13.0*MM     ! -11-2=-13
        fc_s2b = 2.0*MM       ! 4-2=2
        fc_u2a = -5.0*MM
        fc_u2b = 5.0*MM
    *endif

    ! Block 起點（沿 pole 軸，從 tip 算）
    fc_bstart = POLE_TOTAL_LEN - fc_pene

    ! [MODIFIED] Block 水平, global 座標, 不用 LOCAL CS
    ! Pole 尾端
    fc_endx = p1x + POLE_TOTAL_LEN*fc_ax
    fc_endy = p1y + POLE_TOTAL_LEN*fc_ay
    fc_endz = p1z + POLE_TOTAL_LEN*fc_az

    ! Entry point (workspace face, pole 尾端往回 PENE)
    fc_entx = fc_endx - fc_pene*fc_ax
    fc_enty = fc_endy - fc_pene*fc_ay
    fc_entz = fc_endz - fc_pene*fc_az

    ! Block Z 範圍 + XY 中心
    *if, fc_incl, GE, 0, THEN
        ! Upper: entry=bottom, outer=top
        fc_zbot = fc_entz
        fc_ztop = fc_entz + BLK_T
        ! Block 中心 = pole 軸在 outer face (top) 的 XY
        ! outer = entry + (BLK_T/sin(tilt))*axis
        fc_dt = BLK_T/sin(TILT_UP)
        fc_cx = fc_entx + fc_dt*fc_ax
        fc_cy = fc_enty + fc_dt*fc_ay
    *else
        ! Lower: pole 從側面穿過 block → block 垂直居中在 pole 軸上
        fc_zbot = fc_endz - BLK_T/2
        fc_ztop = fc_endz + BLK_T/2
        ! Block 中心 = pole 尾端 XY
        fc_cx = fc_endx
        fc_cy = fc_endy
    *endif

    ! XY 方向向量 (水平面, 朝 workspace = azim+180°)
    fc_twx = -cos(fc_azim)
    fc_twy = -sin(fc_azim)
    fc_sdx = sin(fc_azim)
    fc_sdy = -cos(fc_azim)

    ! --- Block Part 1: 8 角點 (global) ---
    *get, KP_NUM, KP, , NUM, MAX
    *if, KP_NUM, LT, 1, THEN
        KP_NUM = 0
    *endif
    fc_bkp = KP_NUM + 1
    NUMSTR, KP, fc_bkp

    ! Bottom face (z=fc_zbot), 4 corners: (s1a,u1a) (s1b,u1a) (s1b,u1b) (s1a,u1b)
    K,fc_bkp,  fc_cx+fc_s1a*fc_twx+fc_u1a*fc_sdx, fc_cy+fc_s1a*fc_twy+fc_u1a*fc_sdy, fc_zbot
    K,fc_bkp+1,fc_cx+fc_s1b*fc_twx+fc_u1a*fc_sdx, fc_cy+fc_s1b*fc_twy+fc_u1a*fc_sdy, fc_zbot
    K,fc_bkp+2,fc_cx+fc_s1b*fc_twx+fc_u1b*fc_sdx, fc_cy+fc_s1b*fc_twy+fc_u1b*fc_sdy, fc_zbot
    K,fc_bkp+3,fc_cx+fc_s1a*fc_twx+fc_u1b*fc_sdx, fc_cy+fc_s1a*fc_twy+fc_u1b*fc_sdy, fc_zbot
    ! Top face (z=fc_ztop)
    K,fc_bkp+4,fc_cx+fc_s1a*fc_twx+fc_u1a*fc_sdx, fc_cy+fc_s1a*fc_twy+fc_u1a*fc_sdy, fc_ztop
    K,fc_bkp+5,fc_cx+fc_s1b*fc_twx+fc_u1a*fc_sdx, fc_cy+fc_s1b*fc_twy+fc_u1a*fc_sdy, fc_ztop
    K,fc_bkp+6,fc_cx+fc_s1b*fc_twx+fc_u1b*fc_sdx, fc_cy+fc_s1b*fc_twy+fc_u1b*fc_sdy, fc_ztop
    K,fc_bkp+7,fc_cx+fc_s1a*fc_twx+fc_u1b*fc_sdx, fc_cy+fc_s1a*fc_twy+fc_u1b*fc_sdy, fc_ztop

    V,fc_bkp,fc_bkp+1,fc_bkp+2,fc_bkp+3,fc_bkp+4,fc_bkp+5,fc_bkp+6,fc_bkp+7

    ! --- Block Part 2: 8 角點 ---
    *get, KP_NUM, KP, , NUM, MAX
    fc_bkp2 = KP_NUM + 1
    NUMSTR, KP, fc_bkp2

    K,fc_bkp2,  fc_cx+fc_s2a*fc_twx+fc_u2a*fc_sdx, fc_cy+fc_s2a*fc_twy+fc_u2a*fc_sdy, fc_zbot
    K,fc_bkp2+1,fc_cx+fc_s2b*fc_twx+fc_u2a*fc_sdx, fc_cy+fc_s2b*fc_twy+fc_u2a*fc_sdy, fc_zbot
    K,fc_bkp2+2,fc_cx+fc_s2b*fc_twx+fc_u2b*fc_sdx, fc_cy+fc_s2b*fc_twy+fc_u2b*fc_sdy, fc_zbot
    K,fc_bkp2+3,fc_cx+fc_s2a*fc_twx+fc_u2b*fc_sdx, fc_cy+fc_s2a*fc_twy+fc_u2b*fc_sdy, fc_zbot
    K,fc_bkp2+4,fc_cx+fc_s2a*fc_twx+fc_u2a*fc_sdx, fc_cy+fc_s2a*fc_twy+fc_u2a*fc_sdy, fc_ztop
    K,fc_bkp2+5,fc_cx+fc_s2b*fc_twx+fc_u2a*fc_sdx, fc_cy+fc_s2b*fc_twy+fc_u2a*fc_sdy, fc_ztop
    K,fc_bkp2+6,fc_cx+fc_s2b*fc_twx+fc_u2b*fc_sdx, fc_cy+fc_s2b*fc_twy+fc_u2b*fc_sdy, fc_ztop
    K,fc_bkp2+7,fc_cx+fc_s2a*fc_twx+fc_u2b*fc_sdx, fc_cy+fc_s2a*fc_twy+fc_u2b*fc_sdy, fc_ztop

    V,fc_bkp2,fc_bkp2+1,fc_bkp2+2,fc_bkp2+3,fc_bkp2+4,fc_bkp2+5,fc_bkp2+6,fc_bkp2+7

    ! VADD
    *get, fc_bv2, VOLU, 0, NUM, MAX
    fc_bv1 = fc_bv2 - 1
    VADD, fc_bv1, fc_bv2

    ALLSEL, ALL

    *msg, INFO, fc_pi
     Block for P%I built

*enddo

! 模擬不建 coil 實體 (只用 SOURC36), 但需要 COIL_H 計算 yoke 位置
COIL_H  = 14.0*MM

! ===== [ADDED] 安裝 Yoke =====
! 環形板, 中心在原點, 軸 Z, 在上層 coil 頂面上方
! R_inner=40, R_outer=52, 厚度 2mm

YOKE_RI = 38.0*MM             ! [MODIFIED] 內徑縮小讓導柱不露出
YOKE_RO = 62.5*MM             ! [MODIFIED] 從導磁鐵環.STEP 提取
YOKE_T  = 2.0*MM

! 上層 coil top z: 需要從上層 block 計算
! 上層 entry_z 已在 coil 迴圈中算過, 重新算一次
! 所有上層 pole 的 fc_endz 相同, 取 P2 的
fc_up_endz = fc_tz(2) + POLE_TOTAL_LEN*sin(TILT_UP)
fc_up_entz = fc_up_endz - PENE_UP*sin(TILT_UP)
fc_up_blk_top = fc_up_entz + BLK_T
fc_yoke_zbot = fc_up_blk_top + COIL_H
fc_yoke_ztop = fc_yoke_zbot + YOKE_T

! Yoke 截面 KP (矩形: R_inner~R_outer, zbot~ztop)
*get, KP_NUM, KP, , NUM, MAX
*if, KP_NUM, LT, 1, THEN
    KP_NUM = 0
*endif
fc_ykp = KP_NUM + 1
NUMSTR, KP, fc_ykp

K, fc_ykp,   YOKE_RI, 0, fc_yoke_zbot
K, fc_ykp+1, YOKE_RO, 0, fc_yoke_zbot
K, fc_ykp+2, YOKE_RO, 0, fc_yoke_ztop
K, fc_ykp+3, YOKE_RI, 0, fc_yoke_ztop
! 軸 KP (Z 軸, 通過原點)
K, fc_ykp+4, 0, 0, fc_yoke_zbot
K, fc_ykp+5, 0, 0, fc_yoke_ztop

*get, LI_NUM, LINE, , NUM, MAX
*if, LI_NUM, LT, 1, THEN
    LI_NUM = 0
*endif
fc_yli = LI_NUM + 1
NUMSTR, LINE, fc_yli

L, fc_ykp, fc_ykp+1
L, fc_ykp+1, fc_ykp+2
L, fc_ykp+2, fc_ykp+3
L, fc_ykp+3, fc_ykp

*get, AR_NUM, AREA, , NUM, MAX
*if, AR_NUM, LT, 1, THEN
    AR_NUM = 0
*endif
fc_yar = AR_NUM + 1
NUMSTR, AREA, fc_yar
AL, fc_yli, fc_yli+1, fc_yli+2, fc_yli+3

VROTAT, fc_yar, ,,,, , fc_ykp+4, fc_ykp+5, , 4

ALLSEL, ALL

*msg, INFO
 Yoke built

! ===== [ADDED] 安裝磁場導柱 =====
! 3 根, 連接 yoke → 下層 block, 穿過上層 coil 中心孔
! 簡化為圓柱 R=4mm, 從 lower_block_top 到 yoke_bottom
! XY = 下層 block 中心 (P1, P3, P6)

GP_R = 4.0*MM                 ! 導柱半徑 (取最大截面)
GP_H = 41.0*MM                ! [MODIFIED] 導柱從 yoke 底到 block 底（不伸出）
GP_YOKE_R = 57.5*MM           ! [ADDED] 導柱在 yoke 上的徑向位置 (螺絲孔)

! 下層 block top z (所有下層相同)
fc_lo_endz = fc_tz(1) + POLE_TOTAL_LEN*sin(-TILT_DN)
fc_lo_blk_top = fc_lo_endz + BLK_T/2

! 下層 pole 索引: P1=1, P3=3, P6=6
*dim, fc_gpi, , 3
fc_gpi(1) = 1
fc_gpi(2) = 3
fc_gpi(3) = 6

*do, fc_gi, 1, 3, 1
    fc_idx = fc_gpi(fc_gi)
    fc_azim = fc_ra(fc_idx)

    ! 導柱 XY = 下層 block 中心
    fc_ax = cos(-TILT_DN)*cos(fc_azim)
    fc_ay = cos(-TILT_DN)*sin(fc_azim)
    fc_gcx = fc_tx(fc_idx) + POLE_TOTAL_LEN*fc_ax
    fc_gcy = fc_ty(fc_idx) + POLE_TOTAL_LEN*fc_ay

    ! [MODIFIED] 導柱頂端接 yoke 底面，底端剛好到 block 底
    fc_gz2 = fc_yoke_zbot             ! 導柱頂 = yoke 底面
    fc_gz1 = fc_lo_endz - BLK_T/2    ! [MODIFIED] 導柱底 = lower block 底（不伸出）

    ! 截面 KP (矩形 0~R, z1~z2) + 軸 KP
    *get, KP_NUM, KP, , NUM, MAX
    *if, KP_NUM, LT, 1, THEN
        KP_NUM = 0
    *endif
    fc_gkp = KP_NUM + 1
    NUMSTR, KP, fc_gkp

    K, fc_gkp,   fc_gcx+GP_R, fc_gcy, fc_gz1
    K, fc_gkp+1, fc_gcx+GP_R, fc_gcy, fc_gz2
    K, fc_gkp+2, fc_gcx,      fc_gcy, fc_gz2
    K, fc_gkp+3, fc_gcx,      fc_gcy, fc_gz1

    *get, LI_NUM, LINE, , NUM, MAX
    *if, LI_NUM, LT, 1, THEN
        LI_NUM = 0
    *endif
    fc_gli = LI_NUM + 1
    NUMSTR, LINE, fc_gli

    L, fc_gkp, fc_gkp+1
    L, fc_gkp+1, fc_gkp+2
    L, fc_gkp+2, fc_gkp+3
    L, fc_gkp+3, fc_gkp

    *get, AR_NUM, AREA, , NUM, MAX
    *if, AR_NUM, LT, 1, THEN
        AR_NUM = 0
    *endif
    fc_gar = AR_NUM + 1
    NUMSTR, AREA, fc_gar
    AL, fc_gli, fc_gli+1, fc_gli+2, fc_gli+3

    ! VROTAT 繞垂直軸 (通過導柱中心)
    VROTAT, fc_gar, ,,,, , fc_gkp+2, fc_gkp+3, , 4

    ALLSEL, ALL

    *msg, INFO, fc_gi
     Guide post %I built

*enddo

! ===== [ADDED] 上層 Core =====
! 3 根, 連接 yoke → 上層 block, R=4mm
! XY = 上層 block 中心 (P2, P4, P5)

fc_up_blk_top2 = fc_up_entz + BLK_T

*dim, fc_upi, , 3
fc_upi(1) = 2
fc_upi(2) = 4
fc_upi(3) = 5

*do, fc_ui, 1, 3, 1
    fc_idx = fc_upi(fc_ui)
    fc_azim = fc_ra(fc_idx)

    ! 上層 core XY = 上層 block 中心
    fc_pene_tmp = PENE_UP
    fc_ax_tmp = cos(TILT_UP)*cos(fc_azim)
    fc_ay_tmp = cos(TILT_UP)*sin(fc_azim)
    fc_endx_tmp = fc_tx(fc_idx) + POLE_TOTAL_LEN*fc_ax_tmp
    fc_endy_tmp = fc_ty(fc_idx) + POLE_TOTAL_LEN*fc_ay_tmp
    fc_endz_tmp = fc_tz(fc_idx) + POLE_TOTAL_LEN*sin(TILT_UP)
    fc_entx_tmp = fc_endx_tmp - fc_pene_tmp*fc_ax_tmp
    fc_enty_tmp = fc_endy_tmp - fc_pene_tmp*fc_ay_tmp
    fc_dt_tmp = BLK_T/sin(TILT_UP)
    fc_ucx = fc_entx_tmp + fc_dt_tmp*fc_ax_tmp
    fc_ucy = fc_enty_tmp + fc_dt_tmp*fc_ay_tmp

    ! Core Z: 上層 block top → yoke bottom
    fc_ucz1 = fc_up_blk_top2
    fc_ucz2 = fc_yoke_zbot

    ! 截面 + 軸 KP
    *get, KP_NUM, KP, , NUM, MAX
    *if, KP_NUM, LT, 1, THEN
        KP_NUM = 0
    *endif
    fc_uckp = KP_NUM + 1
    NUMSTR, KP, fc_uckp

    K,fc_uckp,  fc_ucx+GP_R, fc_ucy, fc_ucz1
    K,fc_uckp+1,fc_ucx+GP_R, fc_ucy, fc_ucz2
    K,fc_uckp+2,fc_ucx,      fc_ucy, fc_ucz2
    K,fc_uckp+3,fc_ucx,      fc_ucy, fc_ucz1

    *get, LI_NUM, LINE, , NUM, MAX
    fc_ucli = LI_NUM + 1
    NUMSTR, LINE, fc_ucli
    L,fc_uckp,fc_uckp+1
    L,fc_uckp+1,fc_uckp+2
    L,fc_uckp+2,fc_uckp+3
    L,fc_uckp+3,fc_uckp

    *get, AR_NUM, AREA, , NUM, MAX
    fc_ucar = AR_NUM + 1
    NUMSTR, AREA, fc_ucar
    AL,fc_ucli,fc_ucli+1,fc_ucli+2,fc_ucli+3

    VROTAT,fc_ucar,,,,,,fc_uckp+2,fc_uckp+3,,4

    ALLSEL, ALL

    *msg, INFO, fc_ui
     Upper core %I built

*enddo

! ===== VADD 所有鋼件 =====
CSYS, 0
ALLSEL, ALL
*get, fc_nv_all, VOLU, 0, NUM, MAX
*msg, INFO, fc_nv_all
 Steel volumes before VADD: %I
FLST, 2, fc_nv_all, 6, ORDE, 2
FITEM, 2, 1
FITEM, 2, -fc_nv_all
VADD, P51X

! ===== 空氣域 =====
SPH_FINE_R = 7.0*MM
AIR_CYL_R  = 80.0*MM
AIR_CYL_H  = 80.0*MM
SPHERE, 0, SPH_FINE_R
fc_air_zc = (fc_yoke_ztop + fc_lo_endz - BLK_T/2)/2
WPOFFS, 0, 0, fc_air_zc - AIR_CYL_H/2
CYL4, 0, 0, AIR_CYL_R, , , , AIR_CYL_H
WPOFFS, 0, 0, -(fc_air_zc - AIR_CYL_H/2)

! ===== VOVLAP + VGLUE =====
ALLSEL, ALL
VOVLAP, ALL
NUMCMP, VOLU
! [MODIFIED] 恢復 VGLUE（POLE_TIP_R 改 40um 後應能通過）
VGLUE, 8, 1, 2, 3, 4, 5, 6

! ===== [ADDED] Spring 參數 (用於 mesh 後 element-level 重新指派 MAT) =====
SPRING_LEN = 6.0*MM
SPRING_MUR = 100

! 計算 6 根 guide post 的 XY 與 spring 段底 z (lower 3 + upper 3)
*dim, fc_sp_cx, , 6
*dim, fc_sp_cy, , 6
*dim, fc_sp_z1, , 6

! Lower P1, P3, P6
*dim, fc_lo_idx, , 3
fc_lo_idx(1) = 1
fc_lo_idx(2) = 3
fc_lo_idx(3) = 6
*do, fc_si, 1, 3, 1
    fc_idx_sp = fc_lo_idx(fc_si)
    fc_az_sp = fc_ra(fc_idx_sp)
    fc_ax_sp = cos(-TILT_DN)*cos(fc_az_sp)
    fc_ay_sp = cos(-TILT_DN)*sin(fc_az_sp)
    fc_sp_cx(fc_si) = fc_tx(fc_idx_sp) + POLE_TOTAL_LEN*fc_ax_sp
    fc_sp_cy(fc_si) = fc_ty(fc_idx_sp) + POLE_TOTAL_LEN*fc_ay_sp
    fc_sp_z1(fc_si) = fc_lo_blk_top
*enddo

! Upper P2, P4, P5
*dim, fc_up_idx2, , 3
fc_up_idx2(1) = 2
fc_up_idx2(2) = 4
fc_up_idx2(3) = 5
*do, fc_si, 1, 3, 1
    fc_idx_sp = fc_up_idx2(fc_si)
    fc_az_sp = fc_ra(fc_idx_sp)
    fc_ax_sp = cos(TILT_UP)*cos(fc_az_sp)
    fc_ay_sp = cos(TILT_UP)*sin(fc_az_sp)
    fc_endx_sp = fc_tx(fc_idx_sp) + POLE_TOTAL_LEN*fc_ax_sp
    fc_endy_sp = fc_ty(fc_idx_sp) + POLE_TOTAL_LEN*fc_ay_sp
    fc_entx_sp = fc_endx_sp - PENE_UP*fc_ax_sp
    fc_enty_sp = fc_endy_sp - PENE_UP*fc_ay_sp
    fc_dt_sp = BLK_T/sin(TILT_UP)
    fc_sp_cx(3+fc_si) = fc_entx_sp + fc_dt_sp*fc_ax_sp
    fc_sp_cy(3+fc_si) = fc_enty_sp + fc_dt_sp*fc_ay_sp
    fc_sp_z1(3+fc_si) = fc_up_blk_top2
*enddo

! ===== 整理與匯出 =====
CSYS, 0
NUMCMP, VOLU
NUMCMP, AREA
NUMCMP, LINE
NUMCMP, KP

*get, fc_nvf, VOLU, 0, NUM, MAX
*msg, INFO, fc_nvf
 Final: %I volumes

SAVE, 'Full_Assembly_round_filleted', 'db'

ALLSEL, ALL
IGESOUT, 'Full_Assembly_round_filleted', 'iges'

! 匯出後若需要 SolidWorks STEP 轉換，修正 unit flag：
! sed -i "s/,1.0,6,,/,1.0,1,,/" Full_Assembly_round_filleted.iges

FINISH

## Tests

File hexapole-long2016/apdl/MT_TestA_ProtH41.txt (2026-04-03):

!****/CWD,'C:\Users\feilong\Desktop\Fei Long Ansys\Magnetic Tweezers LowPermeability'
!****/CWD,'D:\Fei Long ANSYS\Magnetic Tweezers LowPermeability'
/CWD,'C:\Users\pmero\Documents\Lab406\magnetic-tweezers-sim\hexapole-long2016\results\testA'   ! [MODIFIED] Test A: PROT_H=41mm

Finish
/cle

/CLEAR,NOSTART

/TITLE, 3D Magnetic tweezers magnetic field analysis
/FILNAME,3D MT magnetic field,1

/PREP7

! **** CHange BackGround color to white: ****
/RGB,INDEX,100,100,100, 0   
/RGB,INDEX, 80, 80, 80,13   
/RGB,INDEX, 60, 60, 60,14   
/RGB,INDEX, 0, 0, 0,15  
/REPLOT

! -------------------------------
! ******** MODELING: ************
! -------------------------------
MESH_SIZE = 5

POLE_NUM = 6
COUNTER  = 0

*dim, POLE_ARRAY,,  POLE_NUM
*dim, PROT_ARRAY,,  POLE_NUM

*afun, DEG   !----Using degree
BTOL, 1e-6   !----BoOL tolerence
/UNITS, MKS

R_norm    = 500e-6       !----working radius
R_norm_xy = R_norm*sqrt(2.0/3.0)
R_norm_z  = R_norm/sqrt(3.0)

YOKE_IN_R  = 84e-3/2.0    !----Inner radius of yoke
YOKE_OUT_R = 106e-3/2.0
YOKE_MID_R = (YOKE_IN_R + YOKE_OUT_R)/2.0
YOKE_H     = 2.0e-3
PROT_R     = 10.0e-3/2.0
PROT_H     = 41.0e-3    ! [MODIFIED] Test A: 7mm → 41mm (like Hung GP)

POLE_R        = 6.0e-3/2
POLE_TIP_R    = 40.0e-6    !----40um
POLE_CONE_LEN = 15e-3
POLE_CONE_HYP = sqrt(POLE_CONE_LEN**2 + POLE_R**2)
ANG1 = acos(POLE_R/POLE_CONE_HYP)
ANG2 = 90 - ANG1
L = POLE_CONE_LEN*POLE_TIP_R/POLE_R
POLE_TIP_CENTER = L/cos(ANG2)
POLE_CONE2_LEN  = L*cos(ANG2)
POLE_TIP_R2     = POLE_TIP_R*cos(ANG2)
POLE_TIP_FILLET_DROP = POLE_TIP_CENTER - POLE_TIP_R
POLE_TIP_FILLET_PROT = (POLE_CONE2_LEN - POLE_TIP_FILLET_DROP)

MT_CTR_ZOFST = -PROT_H - 6.0e-3 + R_norm_z

! -------------------------------
! ******* YOKE MODELING: ********
! -------------------------------
WPLANE, 1,0,0,0,,,,,,
WPcsys,-1,0

! **** 1 yoke: ****
CYL4,0,0,YOKE_IN_R,0,YOKE_OUT_R,360,YOKE_H

! **** 6 protrusion: ****
*do, prot_ind, 1, POLE_NUM,1
		
	WPLANE,1,0,0,0,,,,,,
	WPcsys,-1,0

        *if, prot_ind,LE,3, then
                temp_prot_h = -PROT_H
		temp_prot_ang = 120*(prot_ind - 1)
	*else
		WPOFFS,0,0,YOKE_H
		temp_prot_h = PROT_H
		temp_prot_ang = 120*(prot_ind - 4) + 60
	*endif

	CYL4,YOKE_MID_R*cos(temp_prot_ang),YOKE_MID_R*sin(temp_prot_ang),PROT_R, ,,,temp_prot_h
*enddo

! **** Unite the yoke and protrusion: ****
FLST,2, 1 + POLE_NUM, 6,ORDE, 2
FITEM,2, 1
FITEM,2,-(1+POLE_NUM)
VADD,P51X

*get, vol_yoke_ind, VOLU,,NUM, MAX

! ----------------------------
! **** 3 lower poles: ********
! ----------------------------
X0_LOW = YOKE_MID_R*cos(0)
Y0_LOW = YOKE_MID_R*sin(0)
Z0_LOW = -PROT_H

*do, pole_ind,1,3,1

	WPLANE, 1,0,0,0,,,,,,
	WPcsys,-1,0
        ROTA_ANG = 120*(pole_ind-1)
	WPROTA, ROTA_ANG,    !----Rotate about z axis

	*get, VL_NUM, VOLU, ,NUM, MAX
	VL_START = VL_NUM + 1
	numstr, VOLU, VL_START

	! **** Lower pole holer: ****
	BLOCK, X0_LOW - 5e-3,  X0_LOW + 11e-3, Y0_LOW - 5e-3,  Y0_LOW + 5e-3,  Z0_LOW - 10e-3, Z0_LOW          !----index: VL_START
	BLOCK, X0_LOW - 5e-3,  X0_LOW - 2e-3,  Y0_LOW - 10e-3, Y0_LOW + 10e-3, Z0_LOW - 10e-3, Z0_LOW - 5e-3
	BLOCK, X0_LOW - 10e-3, X0_LOW - 2e-3,  Y0_LOW - 5e-3,  Y0_LOW + 5e-3,  Z0_LOW - 10e-3, Z0_LOW - 2e-3
	BLOCK, X0_LOW - 10e-3, X0_LOW - 5e-3,  Y0_LOW - 10e-3, Y0_LOW + 10e-3, Z0_LOW - 10e-3, Z0_LOW - 5e-3

	! **** Key points & line: ****
	*get, KP_NUM, KP  , ,NUM, MAX
	*get, LI_NUM, LINE, ,NUM, MAX
	KP_START = KP_NUM + 1
	LI_START = LI_NUM + 1
	numstr, KP,   KP_START
	numstr, LINE, LI_START

	l1 = R_norm_xy
        l1_ang = atan2( 0 , R_norm_xy )

        l2 = sqrt( (R_norm_xy + POLE_TIP_FILLET_PROT)**2 + POLE_TIP_R2**2 )
	l2_ang = atan2( POLE_TIP_R2 , (R_norm_xy + POLE_TIP_FILLET_PROT) )

	POLE_CONE_LEN_SHIFT = POLE_CONE_LEN + (R_norm_xy - POLE_TIP_FILLET_DROP)
	l3 = sqrt( POLE_CONE_LEN_SHIFT**2 + POLE_R**2 )
	l3_ang = atan2( POLE_R , POLE_CONE_LEN )

	l4 = sqrt( (X0_LOW - 10e-3)**2 + POLE_R**2 )
	l4_ang = atan2( POLE_R , (X0_LOW - 10e-3) )

	l5 = abs( X0_LOW - 10e-3 )
	l5_ang = atan2( 0 , (X0_LOW - 10e-3) )

	l6 = abs( R_norm_xy + POLE_TIP_R )
	l6_ang = atan2( 0, R_norm_xy + POLE_TIP_R )

	K , , l1*cos(ROTA_ANG + l1_ang) , l1*sin(ROTA_ANG + l1_ang), Z0_LOW - 6e-3
	K , , l2*cos(ROTA_ANG + l2_ang) , l2*sin(ROTA_ANG + l2_ang), Z0_LOW - 6e-3
	K , , l3*cos(ROTA_ANG + l3_ang) , l3*sin(ROTA_ANG + l3_ang), Z0_LOW - 6e-3
	K , , l4*cos(ROTA_ANG + l4_ang) , l4*sin(ROTA_ANG + l4_ang), Z0_LOW - 6e-3
	K , , l5*cos(ROTA_ANG + l5_ang) , l5*sin(ROTA_ANG + l5_ang), Z0_LOW - 6e-3
	K , , l6*cos(ROTA_ANG + l6_ang) , l6*sin(ROTA_ANG + l6_ang), Z0_LOW - 6e-3  !---- for arc generation

	LARC , KP_START , KP_START + 1 , KP_START + 5 , POLE_TIP_R
	L , KP_START + 1 , KP_START + 2,,,,,,,,
	L , KP_START + 2 , KP_START + 3,,,,,,,,
	L , KP_START + 3 , KP_START + 4,,,,,,,,
	L , KP_START + 4 , KP_START,,,,,,,,

	! **** Create Area: ****
	*get, AR_NUM, AREA, ,NUM, MAX
	AR_START = AR_NUM + 1
	numstr, AREA, AR_START

	AL, LI_START, LI_START + 1, LI_START + 2, LI_START + 3, LI_START + 4

	! **** Rotate area to get volume: ****
	VROTAT, AR_START, ,,,,,KP_START,KP_START + 4,,4

	! **** Unite the volumn: ****
	*get, vl_ind_temp, VOLU,,NUM,MAX
	FLST,2,(vl_ind_temp - VL_START + 1),6,ORDE,2
	FITEM,2,VL_START
	FITEM,2,-vl_ind_temp
	VADD,P51X

	*get, vol_pole_ind, VOLU,,NUM,MAX
	VADD, VL_NUM, vol_pole_ind

	*get, vol_unite_ind, VOLU,,NUM,MAX

	BLOCK,0,X0_LOW - 10e-3,Y0_LOW - 10e-3,Y0_LOW + 10e-3,Z0_LOW - 6e-3, Z0_LOW

	VSBV, vol_unite_ind,vol_unite_ind + 1

	GPLOT

*enddo

! ---------------------------
! **** 3 upper pole: ********
! ---------------------------
	X0_HIGH = YOKE_MID_R*cos(0)
	Y0_HIGH = YOKE_MID_R*sin(0)
	Z0_HIGH = YOKE_H + PROT_H

*do, pole_ind,4,6,1
	WPLANE, 1,0,0,0,,,,,,
	WPcsys,-1,0
        ROTA_ANG = 120*(pole_ind-4) + 60
	WPROTA, ROTA_ANG, 

	*get, VL_NUM, VOLU, ,NUM, MAX
	VL_START = VL_NUM + 1
	numstr, VOLU, VL_START

	! **** Upper pole holder: ****
	BLOCK, X0_HIGH - 3.5e-3,  X0_HIGH + 8.5e-3, Y0_HIGH - 5e-3,  Y0_HIGH + 5e-3,  Z0_HIGH, Z0_HIGH + 10e-3
	BLOCK, X0_HIGH - 6.5e-3,  X0_HIGH - 3.5e-3, Y0_HIGH - 11e-3, Y0_HIGH + 11e-3, Z0_HIGH, Z0_HIGH + 10e-3
	BLOCK, X0_HIGH - 16.5e-3, X0_HIGH - 6.5e-3, Y0_HIGH - 11e-3, Y0_HIGH + 11e-3, Z0_HIGH, Z0_HIGH + 10e-3

        tip_upper_x = R_norm_xy*cos(ROTA_ANG)
        tip_upper_y = R_norm_xy*sin(ROTA_ANG)
	tip_upper_z = Z0_LOW - 6e-3 + R_norm_z*2
	
	end_upper_x0 = X0_HIGH - 11.5e-3
	end_upper_y0 = Y0_HIGH
        end_upper_z0 = Z0_HIGH + 5e-3
	end_upper_x = sqrt( end_upper_x0**2 + end_upper_y0**2 )*cos(ROTA_ANG)
	end_upper_y = sqrt( end_upper_x0**2 + end_upper_y0**2 )*sin(ROTA_ANG)
	end_upper_z = end_upper_z0

	INCLINE_VECTORx = end_upper_x - tip_upper_x
	INCLINE_VECTORy = end_upper_y - tip_upper_y
	INCLINE_VECTORz = end_upper_z - tip_upper_z

	INCLINE_ANG = atan2( INCLINE_VECTORz, sqrt(INCLINE_VECTORx**2+INCLINE_VECTORy**2) )

	! **** Key points & line: ****
	*get, KP_NUM, KP  , ,NUM, MAX
	*get, LI_NUM, LINE, ,NUM, MAX
	KP_START = KP_NUM + 1
	LI_START = LI_NUM + 1
	numstr, KP,   KP_START
	numstr, LINE, LI_START

        p1x = tip_upper_x
	p1y = tip_upper_y
	p1z = tip_upper_z
	
        p2x = p1x + POLE_TIP_FILLET_PROT*cos(INCLINE_ANG)*cos(ROTA_ANG) - POLE_TIP_R2*sin(ROTA_ANG)
	p2y = p1y + POLE_TIP_FILLET_PROT*cos(INCLINE_ANG)*sin(ROTA_ANG) + POLE_TIP_R2*cos(ROTA_ANG)
        p2z = p1z + POLE_TIP_FILLET_PROT*sin(INCLINE_ANG)

	POLE_CONE_LEN_SHIFT = POLE_CONE_LEN + (R_norm_xy - POLE_TIP_FILLET_DROP)
	p3x = p1x + POLE_CONE_LEN_SHIFT*cos(INCLINE_ANG)*cos(ROTA_ANG) - POLE_R*sin(ROTA_ANG)
	p3y = p1y + POLE_CONE_LEN_SHIFT*cos(INCLINE_ANG)*sin(ROTA_ANG) + POLE_R*cos(ROTA_ANG)
	p3z = p1z + POLE_CONE_LEN_SHIFT*sin(INCLINE_ANG)

	p4x = end_upper_x - POLE_R*sin(ROTA_ANG)
	p4y = end_upper_y + POLE_R*cos(ROTA_ANG)
	p4z = end_upper_z

	p5x = end_upper_x
	p5y = end_upper_y
	p5z = end_upper_z

        p6x = p1x + POLE_CONE_LEN*cos(INCLINE_ANG)*cos(ROTA_ANG)
	p6y = p1y + POLE_CONE_LEN*cos(INCLINE_ANG)*sin(ROTA_ANG)
        p6z = p1z + POLE_CONE_LEN*sin(INCLINE_ANG)

	K,, p1x , p1y , p1z
	K,, p2x , p2y , p2z
	K,, p3x , p3y , p3z
	K,, p4x , p4y , p4z
	K,, p5x , p5y , p5z
	K,, p6x , p6y , p6z

        LARC , KP_START , KP_START + 1 , KP_START + 5 , POLE_TIP_R
	L , KP_START + 1 , KP_START + 2,,,,,,,,
	L , KP_START + 2 , KP_START + 3,,,,,,,,
	L , KP_START + 3 , KP_START + 4,,,,,,,,
	L , KP_START + 4 , KP_START,,,,,,,,

	! **** Create Area: ****
	*get, AR_NUM, AREA, ,NUM, MAX
	AR_START = AR_NUM + 1
	numstr, AREA, AR_START

	AL, LI_START, LI_START + 1, LI_START + 2, LI_START + 3, LI_START + 4

	! **** Rotate area to get volume: ****
	VROTAT, AR_START, ,,,,,KP_START,KP_START + 4,,4
        
	! **** Unite the volumn: ****
	*get, vl_ind_temp, VOLU,,NUM,MAX
	FLST,2,(vl_ind_temp - VL_START + 1),6,ORDE,2
	FITEM,2,VL_START
	FITEM,2,-vl_ind_temp
	VADD,P51X

	*get, vol_pole_ind, VOLU,,NUM,MAX
	VADD, VL_NUM, vol_pole_ind

	GPLOT

*enddo

NUMCMP,VOLU  !----compress volume number
V_ID_MT = 1

!--------------------------
! **** Create Sphere: *****
!--------------------------
SPH_FINE_R = 7e-3    !----diameter of fine element
SPH_OFST = Z0_LOW - 6e-3 + R_norm_z
AIR_CYL_R = 80e-3
AIR_CYL_H = 130e-3      ! [MODIFIED] 加大空氣域容納 PROT_H=41mm

WPLANE, 1,0,0,0,,,,,,
WPcsys,-1,0
WPOFFS,0,0,SPH_OFST

SPHERE, 0, SPH_FINE_R, 0,360  !---- fine sphere

WPOFFS,0,0, -SPH_OFST + YOKE_H/2 - AIR_CYL_H/2
CYL4,0,0,AIR_CYL_R, ,,,AIR_CYL_H   !----Outer Air Cylinder

V_ID_AIR_SPH = 2
V_ID_AIR_CYL = 3

!-------------------
! **** OverLap: ****
!-------------------
VOVLAP,ALL
NUMCMP,VOLU

V_ID_P5 = 1
V_ID_P3 = 2
V_ID_P1 = 3
V_ID_P2 = 4
V_ID_P6 = 5
V_ID_P4 = 6
V_ID_MT = 8
V_ID_AIR_SPH = 7
V_ID_AIR_CYL = 9

VGLUE , V_ID_MT , V_ID_P1 , V_ID_P2 , V_ID_P3 , V_ID_P4 , V_ID_P5 , V_ID_P6

/COLOR , VOLU , RED , V_ID_AIR_SPH , V_ID_AIR_SPH , 1  !----inner
/TRLCY , VOLU , 0.5 , V_ID_AIR_SPH

/COLOR , VOLU , BLUE , V_ID_AIR_CYL , V_ID_AIR_CYL , 1     !----outer
/TRLCY , VOLU , 0.7  , V_ID_AIR_CYL

/REPLOT
VPLOT

!-----------------------------
! **** Magnetic analysis: ****
!-----------------------------

!**** material defination: ****
MAT_AIR1 = 1   !----MAT number 1: Center air
MAT_MT   = 2   !----MAT number 2: magnetic tweezers
MAT_AIR2 = 3   !----MAT number 3: outer air
mp , murx , MAT_AIR1 , 1     !----MAT NUM 1 : center air
mp , murx , MAT_MT   , 280   !----MAT NUM 2 : 1018 steel
mp , murx , MAT_AIR2 , 1     !----MAT NUM 3 : outer air

!**** element defination: ****
ET_nocurr = 1
ET_curr   = 2
ET , ET_nocurr , SOLID96
ET , ET_curr   , SOURC36

!**** define current sources: *****
COIL_OUT_R = 8e-3
COIL_IN_R  = 5e-3
*dim, CURR_ARRAY,,POLE_NUM
CURR_ARRAY(1) = 1
CURR_ARRAY(2) = 0
CURR_ARRAY(3) = 0
CURR_ARRAY(4) = 0
CURR_ARRAY(5) = 0
CURR_ARRAY(6) = 0
TURNS = 70
COIL_THK = COIL_OUT_R - COIL_IN_R
COIL_R = (COIL_IN_R + COIL_OUT_R)/2
COIL_H = 7.0e-3         ! [MODIFIED] 解耦：coil DZ 維持 7mm（不隨 PROT_H 變）
R,1,1,TURNS*CURR_ARRAY(1),COIL_THK,COIL_H   !----Real const set: set 1, 1:represent coil, 
R,2,1,TURNS*CURR_ARRAY(2),COIL_THK,COIL_H   !----Real const set: set 2, 1:represent coil, 
R,3,1,TURNS*CURR_ARRAY(3),COIL_THK,COIL_H   !----Real const set: set 3, 1:represent coil, 
R,4,1,TURNS*CURR_ARRAY(4),COIL_THK,COIL_H   !----Real const set: set 4, 1:represent coil, 
R,5,1,TURNS*CURR_ARRAY(5),COIL_THK,COIL_H   !----Real const set: set 5, 1:represent coil, 
R,6,1,TURNS*CURR_ARRAY(6),COIL_THK,COIL_H   !----Real const set: set 6, 1:represent coil, 

WPLANE, 1,0,0,0,,,,,,
WPcsys,-1,0

NUMCMP,NODE   !----compress node index

*get, NODE_NUM,NODE,,NUM,MAX
NODE_START = NODE_NUM + 1

! **** lower coils: ****
*do, pole_ind,1,3,1

	ROTA_ANG = 120*(pole_ind-1)
	X0_LOW = YOKE_MID_R*cos(ROTA_ANG)
	Y0_LOW = YOKE_MID_R*sin(ROTA_ANG)
	Z0_LOW = -PROT_H

        node1 = NODE_START + 3*(pole_ind-1)
	node2 = NODE_START + 3*(pole_ind-1) + 1
	node3 = NODE_START + 3*(pole_ind-1) + 2
	N , node1 , X0_LOW + COIL_R , Y0_LOW          , Z0_LOW + COIL_H/2
	N , node2 , X0_LOW          , Y0_LOW + COIL_R , Z0_LOW + COIL_H/2
	N , node3 , X0_LOW          , Y0_LOW          , Z0_LOW + COIL_H/2
	TYPE,ET_curr   !----element type
	REAL,pole_ind  !----real const set num
	E,node1,node2,node3
	/ESHAPE,1      !----Use real constants or section definition to form a solid shape display
*enddo

! **** upper coils: ****
*do, pole_ind,4,6,1

	ROTA_ANG = 120*(pole_ind-4) + 60
	X0_HIGH = YOKE_MID_R*cos(ROTA_ANG)
	Y0_HIGH = YOKE_MID_R*sin(ROTA_ANG)
	Z0_HIGH = YOKE_H + PROT_H

        node1 = NODE_START + 3*(pole_ind-1)
	node2 = NODE_START + 3*(pole_ind-1) + 1
	node3 = NODE_START + 3*(pole_ind-1) + 2
	N , node1 , X0_HIGH + COIL_R , Y0_HIGH          , Z0_HIGH - COIL_H/2
	N , node2 , X0_HIGH          , Y0_HIGH + COIL_R , Z0_HIGH - COIL_H/2
	N , node3 , X0_HIGH          , Y0_HIGH          , Z0_HIGH - COIL_H/2
	TYPE,ET_curr   !----element type
	REAL,pole_ind  !----real const set num
	E,node1,node2,node3
	/ESHAPE,1      !----Use real constants or section definition to form a solid shape display
*enddo

! **** mesh magnetic tweezers: ****
VSEL,s,VOLU,,1,6           !----6 poles
VSEL,a,VOLU,,8             !----magnetic tweezers
VATT,MAT_MT,1,ET_nocurr    !----material attribute : material num, real const set num, type num

VSEL,s,VOLU,,V_ID_AIR_SPH  !----Inner air
VATT,MAT_AIR1,1,ET_nocurr

VSEL,s,VOLU,,V_ID_AIR_CYL  !----Outer air
VATT,MAT_AIR2,1,ET_nocurr

ALLSEL,ALL
smrt,MESH_SIZE,,,,,,,,OFF,
mshape,1,3D        !---- 1:mesh shape
mshkey,0           !---- 0:free meshing(defaul)
vmesh,all

! **** Define component: ****
ESEL,S,MAT,,MAT_MT !if you want to plot this element, just use ESEL command and /replot
CM,COMP_MT,ELEM  ! magnetic tweezers as a component

ESEL,S,MAT,,MAT_AIR1
CM,COMP_AIR1,ELEM  ! magnetic tweezers as a component

ESEL,S,MAT,,MAT_AIR2
CM,COMP_AIR2,ELEM  ! magnetic tweezers as a component

!/COLOR , ELEM , BLUE , 1 , 1 , 1    !----coil
!/TRLCY , ELEM , 0.1 , 1 , 1, 1      !----coil

!/COLOR , ELEM , BLUE , 1 , ELEM_MT , 1  !----magnetic tweezers
!/TRLCY , ELEM , 1 , 1 , ELEM_MT, 1      !----magnetic tweezers

!/COLOR , ELEM , RED , ELEM_MT+1 , ELEM_MT+ELEM_AIR_SPH , 1  !----inner air
!/TRLCY , ELEM , 1 , ELEM_MT+1 , ELEM_MT+ELEM_AIR_SPH , 1    !----inner air

!/COLOR , ELEM , BLUE , ELEM_MT+ELEM_AIR_SPH+1 , ELEM_MT+ELEM_AIR_SPH+ELEM_AIR_CYL , 1  !----outer air
!/TRLCY , ELEM , 1 , ELEM_MT+ELEM_AIR_SPH+1 , ELEM_MT+ELEM_AIR_SPH+ELEM_AIR_CYL , 1     !----outer air

/REPLOT

! ------------------------------------------------
! [ADDED] Apply far-field boundary condition
! Set MAG=0 on outer air cylinder boundary surfaces
! so the DSP method (magsolv,3) has a unique solution
! ------------------------------------------------
AIR_CYL_Z_CTR = YOKE_H/2
AIR_CYL_Z_BOT = AIR_CYL_Z_CTR - AIR_CYL_H/2
AIR_CYL_Z_TOP = AIR_CYL_Z_CTR + AIR_CYL_H/2

! [ADDED] Select nodes on lateral cylindrical surface (R = AIR_CYL_R)
LOCAL,11,1,0,0,0                                          ! define local cylindrical CS
CSYS,11                                                    ! activate cylindrical CS
NSEL,S,LOC,X, AIR_CYL_R - 0.5e-3, AIR_CYL_R + 0.5e-3    ! select nodes at R ~ 80mm
CSYS,0                                                     ! switch back to Cartesian

! [ADDED] Also select nodes on top and bottom flat caps
NSEL,A,LOC,Z, AIR_CYL_Z_TOP - 0.5e-3, AIR_CYL_Z_TOP + 0.5e-3
NSEL,A,LOC,Z, AIR_CYL_Z_BOT - 0.5e-3, AIR_CYL_Z_BOT + 0.5e-3

! [ADDED] Apply MAG=0 boundary condition on all selected nodes
D,ALL,MAG,0
ALLSEL,ALL

!-------------------
! **** solving: ****
!-------------------
ALLSEL,ALL
/SOLU
magsolv,3,,,,,1
!SAVE

FINISH

/POST1
/FORMAT,7,,17,9,1000000,
/PAGE,1000000,,1000000
!NLIST,ALL,,,COORD
!PRNSOL,B

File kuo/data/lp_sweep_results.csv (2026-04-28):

L_P_mm | B_peak_mT | IntBdz_uTm | L_m_um | cost_RMS
0.42 | 7.9968 | 5.3535 | 669.46 | 0.02000
0.43 | 8.0631 | 5.4261 | 672.95 | 0.01366
0.44 | 8.1541 | 5.5012 | 674.65 | 0.01471
0.46 | 8.1423 | 5.5581 | 682.62 | 0.01284
0.47 | 8.2041 | 5.6054 | 683.24 | 0.01923
0.48 | 8.2393 | 5.7001 | 691.82 | 0.02847

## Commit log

2026-03-05 Initial commit: 6 ANSYS APDL scripts for Magnetic Tweezers simulation
    Each CoilX.txt runs a separate simulation with only coil X energized,
    for later superposition of magnetic field results.
2026-03-05 Add far-field boundary condition (MAG=0) on outer air cylinder surfaces
    The DSP method (magsolv,3) requires boundary conditions to produce a
    unique solution. Without them, Load Step 2 fails with a negative pivot
    error. This fix selects nodes on the lateral, top, and bottom surfaces
    of the outer air cylinder and sets MAG=0.
2026-03-06 Add reference management system with notes for all 4 papers
    Set up notes-first reading strategy for Claude Code:
    - references/notes/ for structured Markdown notes (tracked)
    - references/pdfs/ for original PDFs (gitignored)
    - references/texts/ for pdftotext extracts (gitignored)
    - .claude/rules/reference-notes.md for reading workflow rules
    Complete notes for 4 papers (2013 lines total):
    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
2026-03-07 Add model validation report and notation glossary
    - notation-glossary.md: unified symbol mapping (dissertation ↔ APDL ↔ MATLAB)
    - model-validation.md: formal comparison of APDL simulation vs Long 2016 dissertation
    - CLAUDE.md: add notation standard section and links to new docs
    - .gitignore: exclude .claude/settings.local.json
2026-03-07 Direct ANSYS temp files to results/ with -dir and -j flags
    MAPDL process temp files (file*.err, file*.log) were landing in the
    launch directory. Adding -dir and -j flags routes them into the
    gitignored results/coilN/ directory with clear jobname prefixes.
    Updated: CLAUDE.md commands, run_remaining_coils.sh, ansys-environment.md
2026-03-08 Add point-charge model fitting for ell and R_a (Eq. 2.1-2.4)
    Implement 6-pole magnetic charge model fitting to ANSYS FEM data:
    - 1D scan over ell with analytical R_a solution (B linear in 1/R_a)
    - Verified 1D = 2D optimization (6 initial guesses, cost ratio = 1.0)
    - Iron exclusion via geometric cone model (~49k/390k nodes)
    - Results: ell=835um, R_a=9.2e8 (vs dissertation 900um, 6.3e8)
    - Baseline ~5% error at WP center attributed to murx=280
2026-03-08 Add fitting derivation docs and dissertation Section 2.2.3 notes
    - charge-model-fitting.md: complete math derivation, implementation
    details, correctness verification, and result diagnostics
    - long-2016-section2.2.3-derivation.md: detailed notes on Eq. 2.1-2.4,
    K_I matrix, fitting process, and K_I^FEM extraction method
2026-03-09 Add parameter space exploration and 6-coil joint fitting scripts
    New analysis scripts:
    - test_19param_fit.m: 19-param free 3D vs 2-param sphere (identifiability test)
    - test_joint_6coil_fit.m: 6-coil joint fit with shared positions + per-coil C_k
    - fit_3d_vector_all_coils.m: 3D vector single-charge fit for all 6 coils
    - fit_charge_model_6coil.m: 6-coil per-coil + joint sphere fitting
    - test_simplified_model.m: 1-charge scalar vs 6-charge comparison
    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
2026-03-09 Update fitting docs with Part IV results; replace old figures
    - charge-model-fitting.md: Add Part IV (§21-29) covering parameter space
    exploration, 7 methods comparison, identifiability analysis, error
    decomposition, and charge-cone geometry analysis
    - Delete whiteboard-fitting-walkthrough.md (content merged into main doc)
    - Replace old verification figures with new dissertation-style figures
    (fig2_3, fig2_4, fig2_6 series)
2026-03-22 Clean up fitting project: keep [A]/[J]/[B-6x], remove intermediate methods
    Remove 8 analysis scripts (methods [a],[D],[B-sc] and variants),
    2 intermediate .mat files, 4 diagnostic figures for deprecated methods.
    Add finalized [B-6x] and [J] scripts, data, and figures.
    Clean fit_all6_with_bias.m: remove [B-sc]/[D] warm-start and comparison code.
    Rename and trim fitting-methods doc to cover only [A]→[J]→[B-6x].
    Update CLAUDE.md architecture and detailed docs sections.
    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
2026-03-22 Add B perpendicularity verification on P1 cone surface
    verify_B_perpendicularity.m checks angle between B and surface
    normal at air-side nodes along P1 cone (s=1-6mm). Result: ~9°
    mean deviation, consistent across cone body. Deviation from
    theoretical 0.2° is due to finite mesh spacing (closest air
    nodes at 90-400um from interface). VSBV flat-cut nodes excluded
    by restricting to lower-half cone (phi < -10°).
2026-03-22 Add Coil5 variant with enlarged fine sphere (SPH_FINE_R=10mm)
    Create independent scripts for P2 cone surface analysis:
    - MT_Modeling_Geometry_Meshing_Solving_Coil5_sph10.txt (SPH_FINE_R=10mm)
    - post_extract_coil5_sph10.txt (output to results/coil5_sph10/)
    Original 6 Coil scripts remain unchanged at SPH_FINE_R=7mm.
    Results: uniform mesh density to s≈9.5mm eliminates the sampling
    discontinuity at the sphere boundary. |B| confirmed to plateau
    at ~6-7 mT for s > 8mm along P2 cone surface.
    13mm and 12mm failed (VOVLAP boolean error — sphere-cone
    intersection too complex). 10mm is the maximum viable radius
    (sphere top at z=-2.7mm, safely below yoke at z=0).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
2026-03-23 Add single-pole APDL scripts: bare pole (Case A) vs pole+yoke (Case B)
2026-03-23 Add yoke effect MATLAB analysis: 9.6x enhancement, shape preserved
    Compares bare pole vs pole+yoke: field enhancement (V1), spatial
    distribution (V2), and magnetic circuit analysis (V3).
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2026-04-03 Add Hung hexapole simulation: APDL, analysis, docs, figures, IGES
    - Add hung/ directory: complete ANSYS magnetostatic simulation for Hung hexapole design
    - apdl/: 6 coil simulation scripts + geometry export + post-processing
    - analysis/: MATLAB figure generation (B-field contours, 3D vectors)
    - docs/: technical documentation (workflow, geometry, troubleshooting)
    - figures/: coil1 B-field results + geometry visualization
    - IGES/: individual part exports (SolidWorks compatible)
    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
    [Coil.iges, Full_Assembly_inch.iges, Mag_Guide_Post.iges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]
2026-04-04 Add IGES_converted: unit-flag-fixed IGES for reliable STEP conversion
    - Copy all IGES from hung/IGES/ to hung/IGES_converted/
    - Fix unit flag from 6 (mm) to 1 (inches) for SolidWorks STEP export
    - Add README explaining difference between raw and converted IGES
    - Update hung/README.md folder structure
    [Coil.iges, Full_Assembly.iges, Mag_Guide_Post.iges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]
2026-04-09 Add 40 um diameter tip fillet to pole geometry
    - Add MT_Hung_SphereModel_filleted.txt: full assembly with 40 um fillet on all 6 pole tips
    - Add export_pole_filleted.txt: standalone single-pole filleted export
    - Geometry: smooth tangent fillet (radius 20 um), cone semi-angle preserved at 11.31 deg
    - Junction shifts from 15.875 -> 15.793 mm (0.082 mm), total length unchanged
    - Foremost point of fillet kept at original tip position (preserves R=0.5mm sphere constraint)
    - Add IGES exports (raw and unit-flag-corrected) for both single pole and full assembly
    - Add MATLAB explanation figures (fillet_explanation, method_A_explanation)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
    [Full_Assembly_filleted.iges, Mag_Pole_Bottom_filleted.iges]
2026-04-11 Add pole variants, sensor analysis, and reorganize figures
    - Add 3 pole variant scripts: filled, filleted (D-shape+R40um), round_filleted
    - Add mesh_steel_only.txt for geometry-only mesh visualization
    - Add point-charge fitting method documentation
    - Add round-pole IGES models (Full_Assembly + Poles)
    - Add B-field figures: contour, vector (2D/3D), P1 cross-section
    - Add sensor position analysis: B vs position, sensitivity, ratio
    - Add hexapole tip annotated geometry figure
    - Reorganize figures: analytic/ for analysis, coilN/ for distributions
    - Fix .gitignore to cover PDFs in subdirectories
    - Update hung/README.md with new structure and results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
    [Full_Assembly_filleted.iges, Full_Assembly_round_filleted.iges, Poles_round_filleted.iges]
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2026-04-20 Reorganize hung/ into subdirectories by role
    - analysis/: core/ fit/ plot/ util/ variants/ (move + rename scripts, add addpath core/)
    - apdl/: geom/ sim/ postproc/ variants/ (rename SphereModel_filleted -> Assembly_Dfillet)
    - scripts/run/: batch shell scripts with variants/ for older versions
    - data/: active .mat at root, variants/ for legacy/orphan + README
    - Update all doc and run-script path references
    Fixes:
    - fit_J.m now saves J_ideal_fit.mat (unblock B6x_1C/6C main-pipeline dependency)
    - Split B6x output into B6x_hung_1C.mat / _6C.mat to avoid overwrite
    - Add rule: hung/IGES/ and hung/IGES_converted/ must stay in sync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
2026-04-20 Update figures/README for new directory structure
    - Replace geometry/ with analytic/ (merged during reorg)
    - List all 18 analytic figures grouped by category (fitting / d-hat / sensor / geometry)
    - List 8 current coil1 B-field plots including variant comparisons
    - Update MATLAB and APDL paths to post-reorg locations
    - Document figure-organization convention (main / fail / analytic)
2026-04-28 Add kuo quadrupole sub-project (FEM sim + L_P fit + IGES)
    4-pole MEMS quadrupole 子專案（Harrison 2014 JMEMS / 2015 PRSTAB 對標）。
    Pole length 已 fit 到 L_P = 0.46 mm（cost RMS 1.28% vs JMEMS Fig 5）。
    CAD/SLDPRT/0.67mm_baseline.SLDPRT - SolidWorks 原始建模（初始猜測 L_P=0.6748 mm）
    CAD/STEP/0.67mm.STEP - 上述 STEP 匯出
    IGES/Quadrupole_Lp067.iges - 初始猜測幾何 (T_Z=55 µm)
    IGES/Quadrupole_Lp067_T100.iges - 初始幾何 (T_Z=100 µm, fit 用)
    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
    [0.67mm.STEP, 0.67mm_baseline.SLDPRT, Quadrupole_Lp046_T100.iges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]
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2026-04-28 Fix Hung tip fillet radius 20→40 µm and migrate CWD to G drive
    Tip fillet 原誤設 20 µm radius（40 µm diameter），與 sim 腳本及 Long 2016 不一致。
    統一為 40 µm radius（80 µm diameter）。同步把硬編 CWD 從前任工作站
    (C:\Users\pmero\...) 改為目前環境 (G:\my_workspace\...)。
    hung/apdl/geom/MT_Hung_Assembly_Dfillet.txt
    - POLE_TIP_R 0.020→0.040 mm；CWD 改 G 槽；
    移除 SAVE 防止 .db 污染 IGES 資料夾；
    加 /EXIT, NOSAV
    hung/apdl/geom/export_pole_filleted.txt
    - POLE_TIP_R 0.020→0.040 mm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
    [Full_Assembly_filleted.iges]
2026-04-28 Add Hung l-sensitivity study (l=250/500 µm variants + figures)
    比較 pole-tip 正交連線一半長度 l = 250 vs 500 µm 對 B 場的影響。
    依 docs/plans/workflow-l-sensitivity.md 流程產出。
    Geometry / IGES：
    hung/apdl/geom/MT_Hung_Assembly_Dfillet_l250.txt - l=250 µm 幾何腳本
    hung/IGES/Full_Assembly_Dfillet_l250.iges - l=250 µm 匯出
    hung/IGES_converted/Full_Assembly_Dfillet_l250.iges - 對應 SolidWorks 版
    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
    [Full_Assembly_Dfillet_l250.iges]
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
